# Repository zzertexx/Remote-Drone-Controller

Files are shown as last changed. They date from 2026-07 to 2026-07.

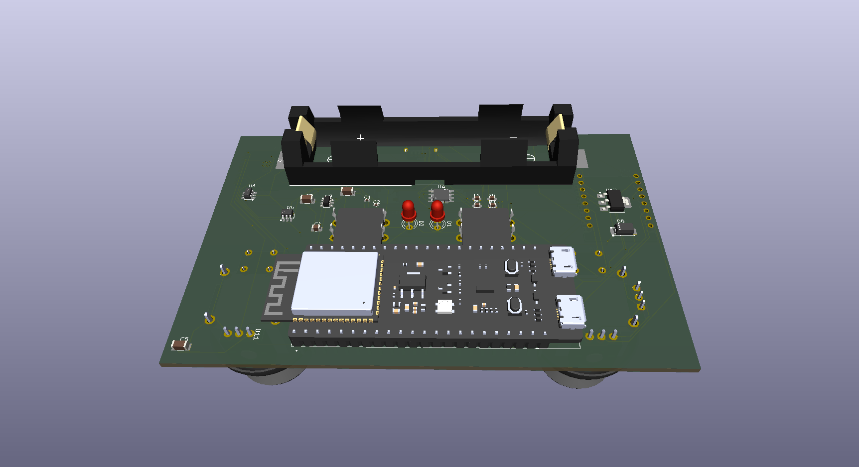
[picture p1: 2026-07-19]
Demo/PCB2.png

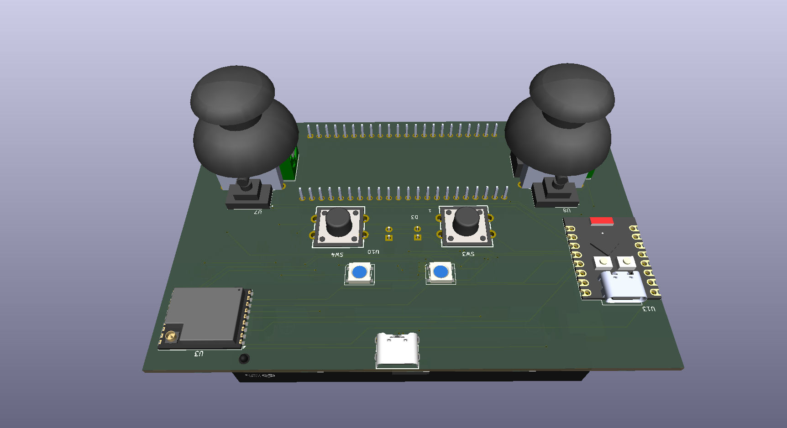
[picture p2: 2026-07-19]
Demo/PCB.png

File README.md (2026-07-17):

# Remote Drone Controller
Remote Controller for my [Drone](https://github.com/zzertexx/drone) with FPV viewer with Phone and Control with Joystick

# How it works
My drone uses ELRS channel to Receive commands and this controller acts as Transmitter on ELRS using SX1280 module while getting joysticks commands from ESP32-C3 that sends them to ESP32-S3.

# How to use it
1. Order PCB
2. Solder all components as stated in Schematics
3. Flash [ELRS firmware](https://github.com/expresslrs/expresslrs) for the main ESP32-S3
4. Flash the companion firmware @ /firmware to the ESP32-C3
5. Power on, bind the controller to drone's ELRS receiver
6. Calibrate joystick min/center/max values.

# Why I designed it?
I designed drone recently, but I don't have controller for it, so I built one

# Bill of Materials
| Name | Quantity |
| --- | --- |
| E28-2G4M27S SX1280 module | 1 pc | 
| ESP32-S3 | 1 pc |
| ESP32-C3 | 1 pc |
| 2.4 GHz antenna  | 1 pc |
| Joystick | 2 pcs |
| TP4056 chip | 1 pc |
| FS8205A chip | 1 pc |
| DW01A chip | 1 pc |
| MT3608 5V converter | 1 pc |
| AMS1117 3.3V converter | 1 pc |
| WS2812 | 2 pcs |
| Tactile Button | 2 pcs |
| Resistors | 1K x3, 1.2K, 100, 4.7K x2, 0, 110K, 15K, 5.1K |
| Inductor 4.7uH | 1 pc |
| Capacitors | 0.1uF x2, 22uF x3, 47uF |
| LED THT D3mm | 2 pcs |
| 2400mAh Battery 18650 | 1 pc |
| Battery Holder | 1 pc |

# Next feautures
3D Enclosure
VTX Video Receiver for Phone

# Photos







# AI DISCLOSURE
AI was used for researching various components, tradeofs and their compatibility

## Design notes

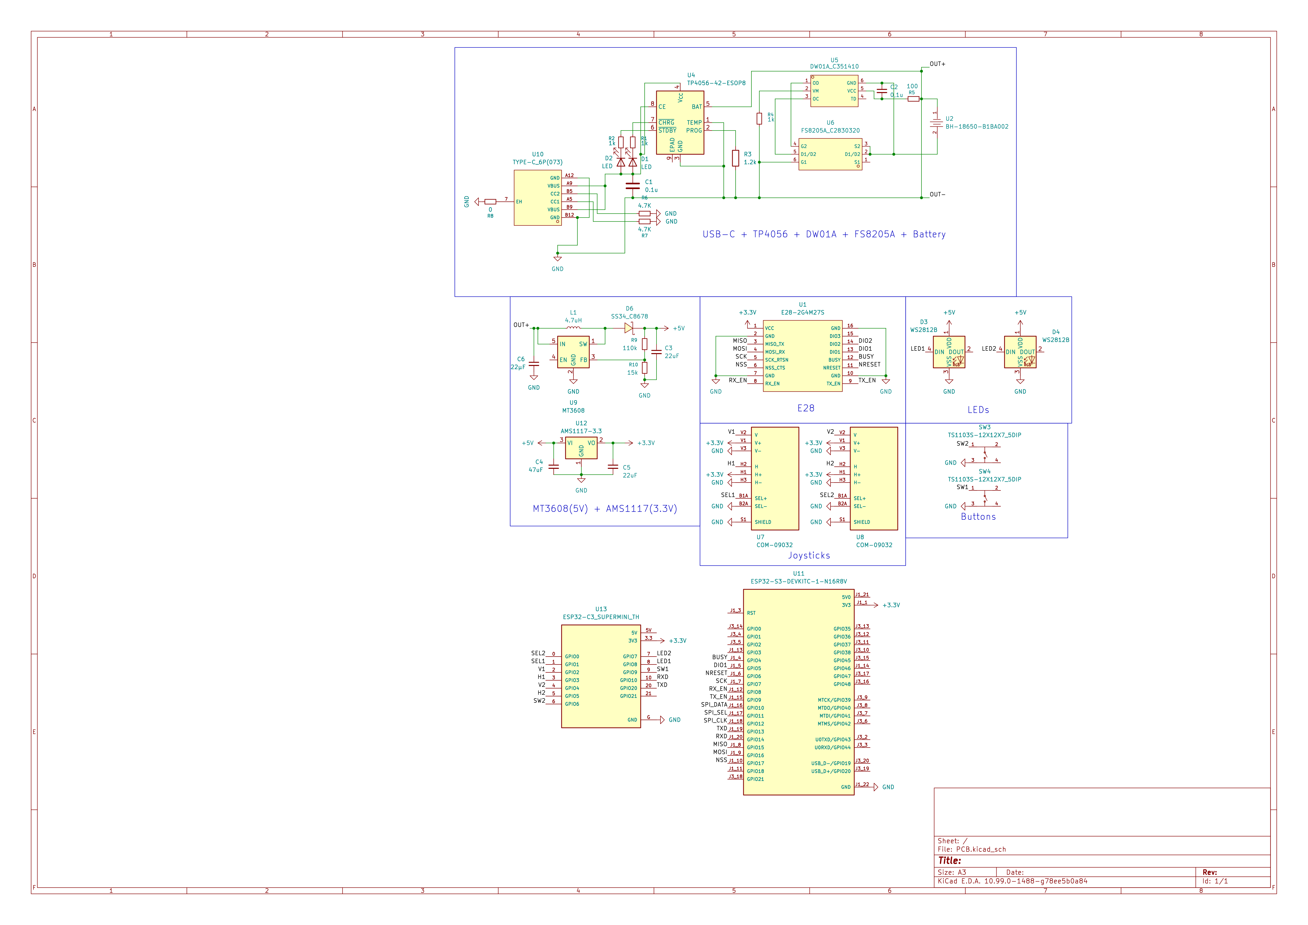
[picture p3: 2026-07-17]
schematics.png

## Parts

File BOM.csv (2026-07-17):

Name | Price USD | Quantity | Link
E28-2G4M27S SX1280 module | 6,2 | 1 | https://item.taobao.com/item.htm?abbucket=3&id=880953544384&ns=1&xxc=taobaoSearch
ESP32-S3N16R8 | 2,22 | 1 | https://item.taobao.com/item.htm?id=872221321968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
MS2107 | 6 | 1 | https://item.taobao.com/item.htm?id=665313273000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
2.4 GHz antenna | 0,6 | 1 | https://detail.tmall.com/item.htm?id=624964877314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
Joystick | 0,6 | 2 | https://detail.tmall.com/item.htm?id=551127183441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
TP4056 chip | 0,07 | 1 | https://item.taobao.com/item.htm?id=981177601023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
DW01A chip | 0,03 | 1 | https://detail.tmall.com/item.htm?abbucket=3&id=762867868512&ns=1&skuId=5253067080369&xxc=taobaoSearch
FS8205A chip | 0,1 | 1 | https://item.taobao.com/item.htm?ali_trackid=282_7bfe62ec76a93e8fbe2256e592906e16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
MT3608 5V converter | 0,037 | 1 | https://item.taobao.com/item.htm?ali_trackid=282_f4fc369ab19dd77611957b498ca91023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
AMS1117 3.3V converter | 0,2 | 1 | https://www.lcsc.com/product-detail/C6186.html?s_z=n_q_AMS1117
WS2812 | 0,74 | 2 | https://item.taobao.com/item.htm?id=522197656009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
Tactile Button | 0,2 | 2 | https://www.lcsc.com/product-detail/C48677982.html?s_z=n_q_t_button
ESP32 C3 | 1,2 | 1 | https://www.lcsc.com/product-detail/C2838500.html?s_z=n_q_p_ESP32%2520C3
Battery Holder | 1,43 | 1 | https://www.lcsc.com/product-detail/C2988620.html?s_z=n_q_t_18650%2520
2400 Battery 18650 | 3,84 | 1 | https://item.taobao.com/item.htm?abbucket=3&id=750556365338&ns=1&xxc=taobaoSearch
THT LEDs 3mm | 0,6 | 1 | https://item.taobao.com/item.htm?id=674866929367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
SS34 Schottky | 0,1 | 1 | https://www.lcsc.com/product-detail/C8678.html?s_z=n_q_x_SS34%2520schottky
22uF capacitor | 0,14 | 3 | https://jlcpcb.com/partdetail/6131-CL31A226KPHNNNE/C5672
47uF capacitor | 0,2 | 1 | https://jlcpcb.com/partdetail/17464-CL21A476MQYNNNE/C16780
0,1uF capacitor | 0,02 | 2 | https://jlcpcb.com/partdetail/1877-CL05B104KO5NNNC/C1525
4.7uH inductor | 0,62 | 1 | https://www.lcsc.com/product-detail/C86090.html
1K resistor | 0,62 | 3 | https://www.lcsc.com/product-detail/C106235.html
1.2K resistor | 0,4 | 1 | https://www.lcsc.com/product-detail/C114605.html
100 resistor | 0,4 | 1 | https://www.lcsc.com/product-detail/C122970.html
4.7K resistor | 0,4 | 2 | https://www.lcsc.com/product-detail/C2907034.html
0 resistor | 0,47 | 1 | https://www.lcsc.com/product-detail/C95177.html
110k resistor | 0,27 | 1 | https://www.lcsc.com/product-detail/C2906984.html
15k resistor | 0,26 | 1 | https://www.lcsc.com/product-detail/C2906995.html
 | 27,967

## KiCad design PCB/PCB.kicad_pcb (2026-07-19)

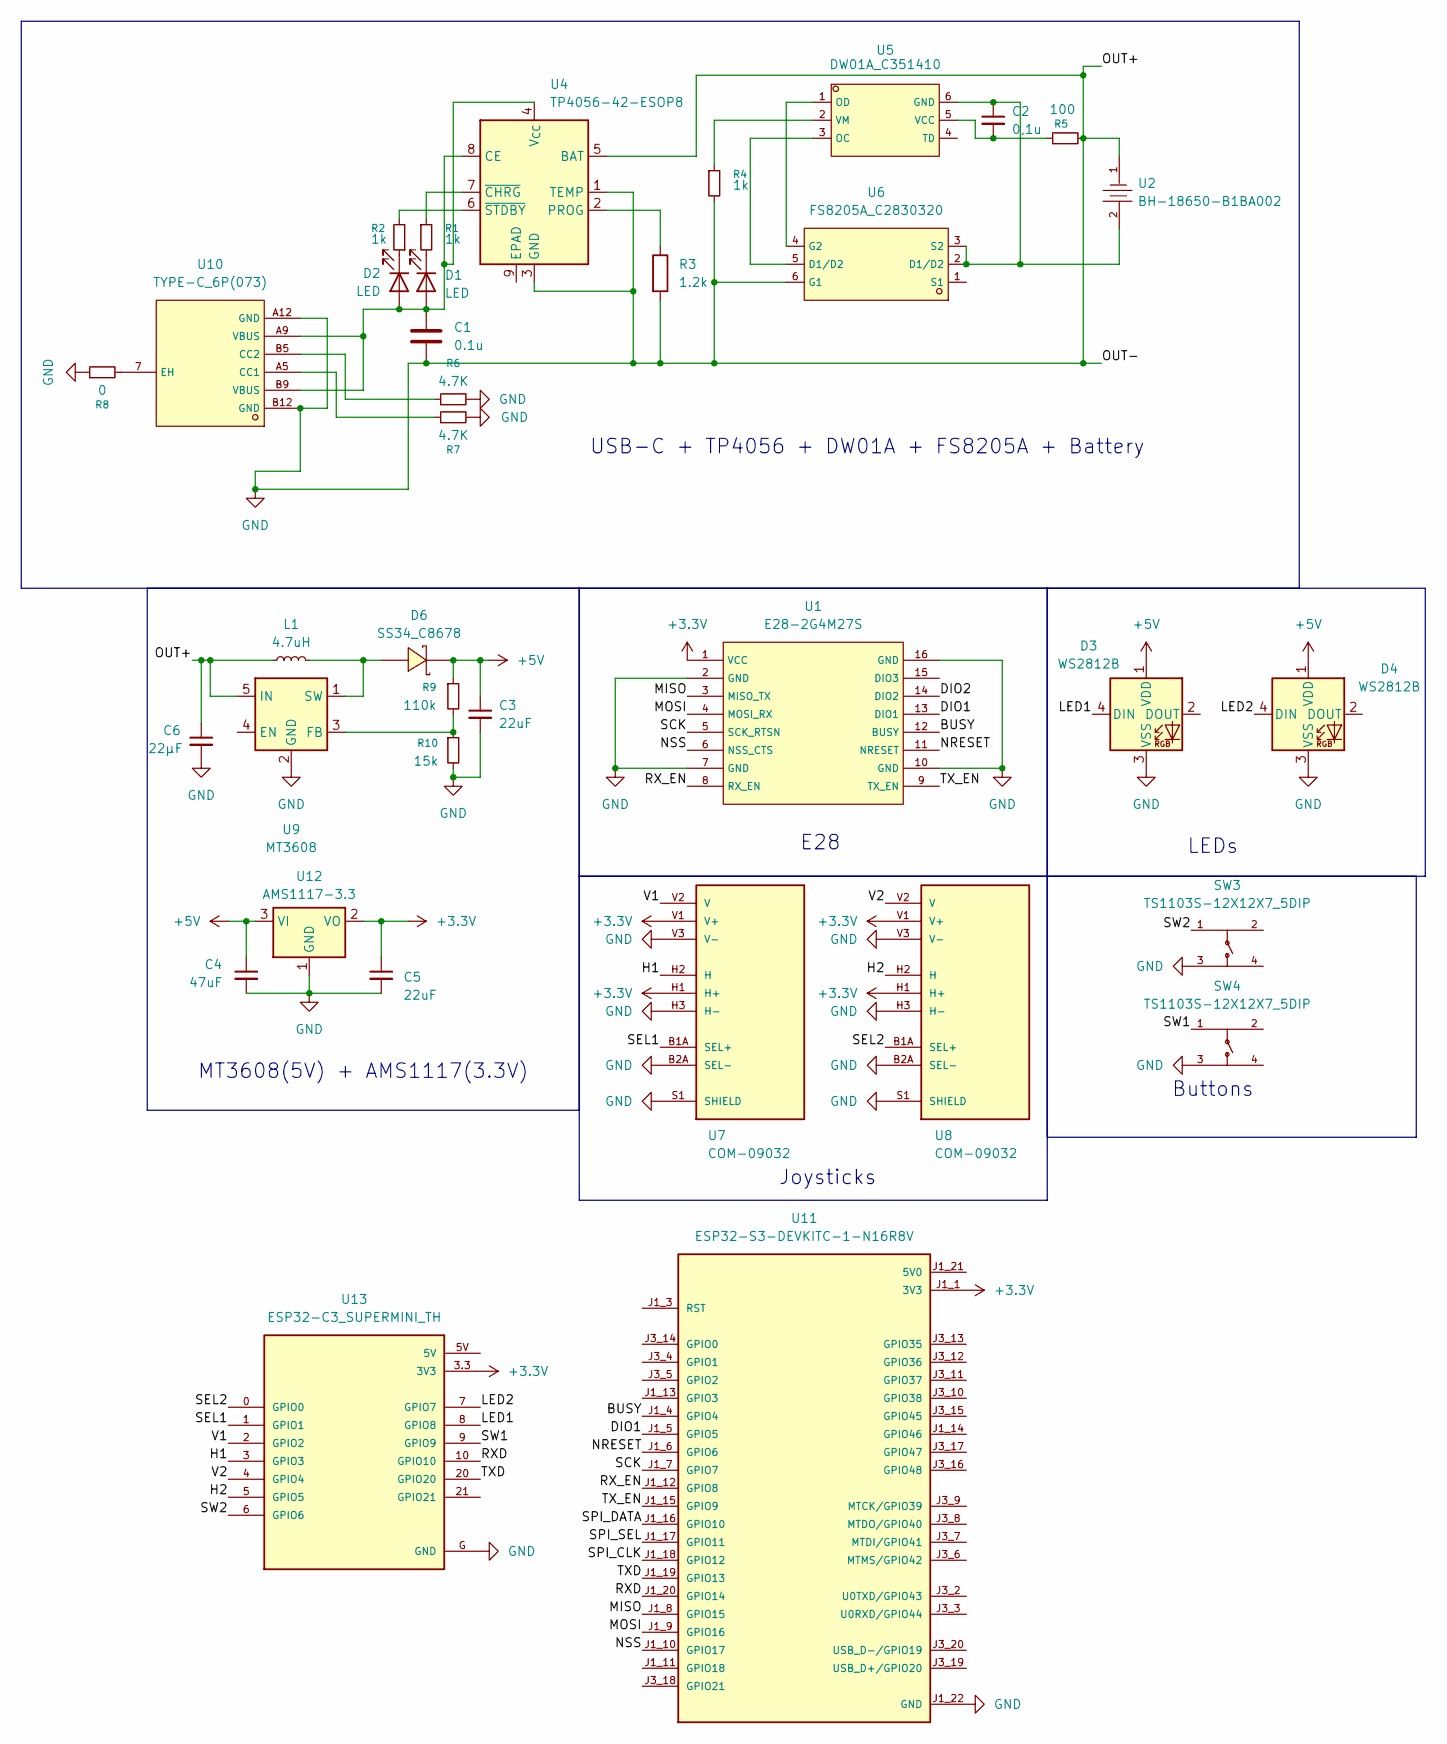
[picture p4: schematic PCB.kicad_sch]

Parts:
C1: 0.1u; C_0402_1005Metric
C2: 0,1u; C_0402_1005Metric
C3, C5: 22uF; C_1206_3216Metric
C4: 47uF; C_0805_2012Metric
C6: 22µF; C_1206_3216Metric
D1, D2: LED; LED_D3.0mm
D3, D4: WS2812B; LED_WS2812B_PLCC4_5.0x5.0mm_P3.2mm
D6: SS34_C8678; SMA_L4.3-W2.6-LS5.2-RD; LCSC C8678
L1: 4.7uH; C_0603_1608Metric
R1, R2, R4: 1k; C_0603_1608Metric
R3: 1.2k; C_0603_1608Metric
R5: 100; C_0603_1608Metric
R6, R7: 4.7K; C_0603_1608Metric
R8: 0; C_0603_1608Metric
R9: 110k; C_0603_1608Metric
R10: 15k; C_0603_1608Metric
SW3, SW4: TS1103S-12X12X7_5DIP; SW-TH_4P-L12.0-W12.0-P5.00-LS12.5; LCSC C48677982
U1: E28-2G4M27S; WIRELM-SMD_E28-2G4M2XS; LCSC C411312
U2: BH-18650-B1BA002; BATTERY-SMD_18650-1S-L77.1-W20.7-1; LCSC C2988620
U4: TP4056-42-ESOP8; SOIC-8-1EP_3.9x4.9mm_P1.27mm_EP2.41x3.3mm_ThermalVias
U5: DW01A_C351410; SOT-23-6_L2.9-W1.6-P0.95-LS2.8-BL; LCSC C351410
U6: FS8205A_C2830320; SOT-23-6_L2.9-W1.6-P0.95-LS2.8-BR; LCSC C2830320
U7, U8: COM-09032; XDCR_COM-09032; PARTREV N/A
U9: MT3608; SOT-23-6
U10: TYPE-C_6P(073); TYPE-C-SMD_TYPE-C-6P-073; LCSC C668623
U11: ESP32-S3-DEVKITC-1-N16R8V; XCVR_ESP32-S3-DEVKITC-1-N16R8V; PARTREV 1.1
U12: AMS1117-3.3; SOT-223-3_TabPin2
U13: ESP32-C3_SUPERMINI_TH; MODULE_ESP32-C3_SUPERMINI_TH

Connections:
+3.3V: C5.1, U1.1 (VCC), U7.H1 (H+), U7.V1 (V+), U8.H1 (H+), U8.V1 (V+), U11.J1_1 (3V3), U11.J1_2 (3V3), U12.2 (VO), U13.3.3 (3V3)
+5V: C3.1, C4.1, D3.1 (VDD), D4.1 (VDD), D6.1 (K), R9.1, U12.3 (VI)
/BUSY: U1.12 (BUSY), U11.J1_4 (GPIO4)
/DIO1: U1.13 (DIO1), U11.J1_5 (GPIO5)
/H1: U7.H2 (H), U13.3 (GPIO3); also elsewhere on the board
/H2: U8.H2 (H), U13.5 (GPIO5); also elsewhere on the board
/LED1: D3.4 (DIN), U13.8 (GPIO8); also elsewhere on the board
/LED2: D4.4 (DIN), U13.7 (GPIO7); also elsewhere on the board
/MISO: U1.3 (MISO_TX), U11.J1_8 (GPIO15)
/MOSI: U1.4 (MOSI_RX), U11.J1_9 (GPIO16)
/NRESET: U1.11 (NRESET), U11.J1_6 (GPIO6)
/NSS: U1.6 (NSS_CTS), U11.J1_10 (GPIO17)
/RXD: U11.J1_20 (GPIO14), U13.10 (GPIO10); also elsewhere on the board
/RX_EN: U1.8 (RX_EN), U11.J1_12 (GPIO8)
/SCK: U1.5 (SCK_RTSN), U11.J1_7 (GPIO7)
/SEL1: U7.B1A (SEL+), U13.1 (GPIO1); also elsewhere on the board
/SEL2: U8.B1A (SEL+), U13.0 (GPIO0); also elsewhere on the board
/SPI_CLK: U11.J1_18 (GPIO12)
/SPI_DATA: U11.J1_16 (GPIO10)
/SPI_SEL: U11.J1_17 (GPIO11)
/SW1: SW4.1, U13.9 (GPIO9); also elsewhere on the board
/SW2: SW3.1, U13.6 (GPIO6); also elsewhere on the board
/TXD: U11.J1_19 (GPIO13), U13.20 (GPIO20); also elsewhere on the board
/TX_EN: U1.9 (TX_EN), U11.J1_15 (GPIO9)
/V1: U7.V2 (V), U13.2 (GPIO2); also elsewhere on the board
/V2: U8.V2 (V), U13.4 (GPIO4); also elsewhere on the board
GND: C1.2, C3.2, C4.2, C5.2, C6.1, C6.2, D3.3 (VSS), D4.3 (VSS), L1.1, R3.2, R4.2, R5.2, R6.2, R7.2, R8.1, R10.2, SW3.3, SW4.3, U1.2 (GND), U1.7 (GND), U1.10 (GND), U1.16 (GND), U2.1, U4.1 (TEMP), U4.3 (GND), U4.5 (BAT), U6.6 (G1), U7.B2A (SEL-), U7.H3 (H-), U7.S1 (SHIELD), U7.S2 (SHIELD), U7.S3 (SHIELD), U7.S4 (SHIELD), U7.V3 (V-), U8.B2A (SEL-), U8.H3 (H-), U8.S1 (SHIELD), U8.S2 (SHIELD), U8.S3 (SHIELD), U8.S4 (SHIELD), U8.V3 (V-), U9.2 (GND), U9.5 (IN), U10.A12 (GND), U10.B12 (GND), U11.J1_22 (GND), U11.J3_1 (GND), U11.J3_21 (GND), U11.J3_22 (GND), U12.1 (GND), U13.G (GND)
unnamed: C1.1, D1.2 (A), D2.2 (A), U4.4 (V_{CC}), U4.8 (CE), U10.A9 (VBUS), U10.B9 (VBUS)
unnamed: D1.1 (K), R1.2
unnamed: D2.1 (K), R2.1
unnamed: D6.2 (A), L1.2, U9.1 (SW)
unnamed: R3.1, U4.2 (PROG)
unnamed: R1.1, U4.7 (~CHRG)
unnamed: R2.2, U4.6 (~STDBY)
unnamed: C2.1, U2.2, U5.6 (GND), U6.2 (D1/D2), U6.3 (S2)
unnamed: U5.3 (OC), U6.5 (D1/D2)
unnamed: U5.1 (OD), U6.4 (G2)
unnamed: C2.2, R5.1, U5.5 (VCC)
unnamed: R4.1, U5.2 (VM)
unnamed: R9.2, R10.1, U9.3 (FB)
unnamed: R7.1, U10.A5 (CC1)
unnamed: R6.1, U10.B5 (CC2)
unnamed: R8.2, U10.7 (EH)

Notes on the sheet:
LEDs
USB-C + TP4056 + DW01A + FS8205A + Battery
MT3608(5V) + AMS1117(3.3V)
Buttons
E28
Joysticks

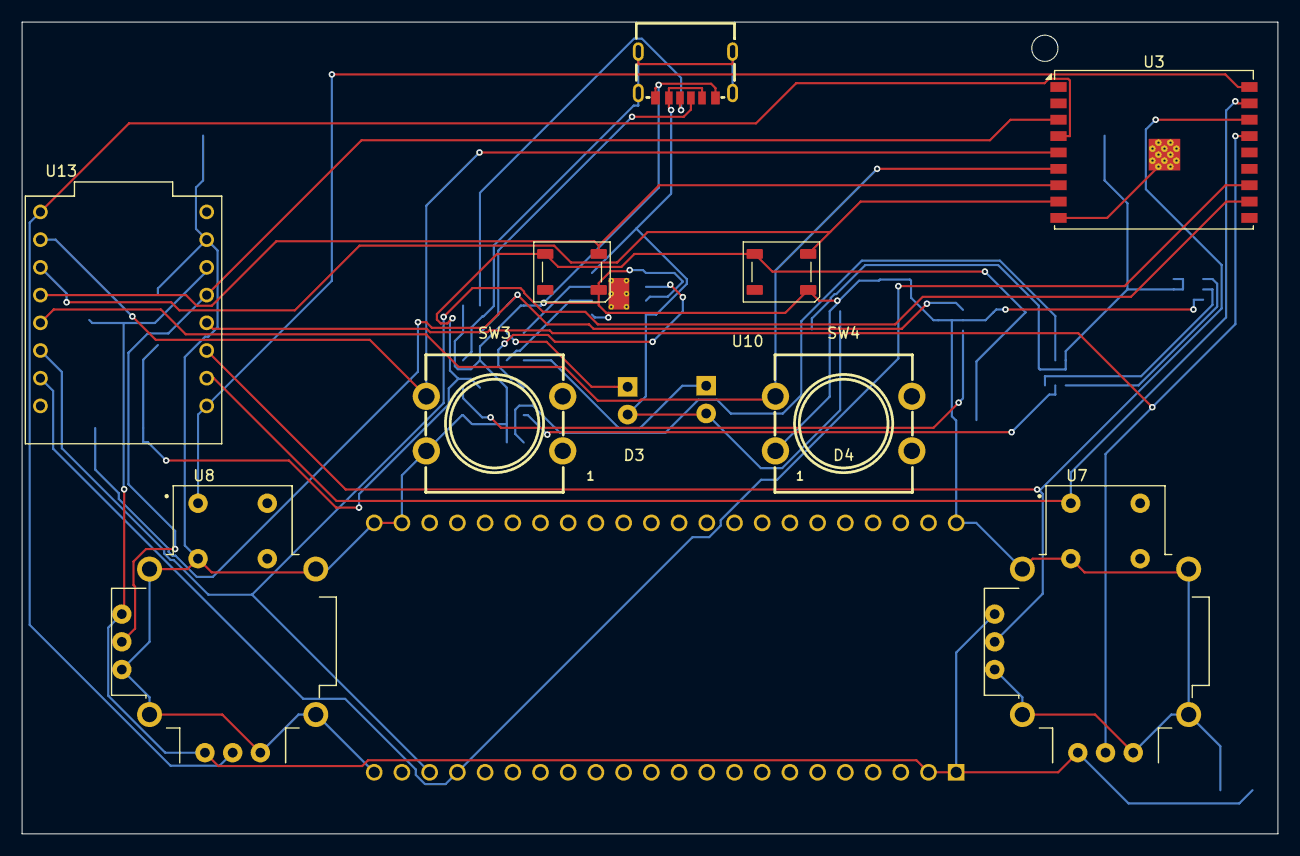
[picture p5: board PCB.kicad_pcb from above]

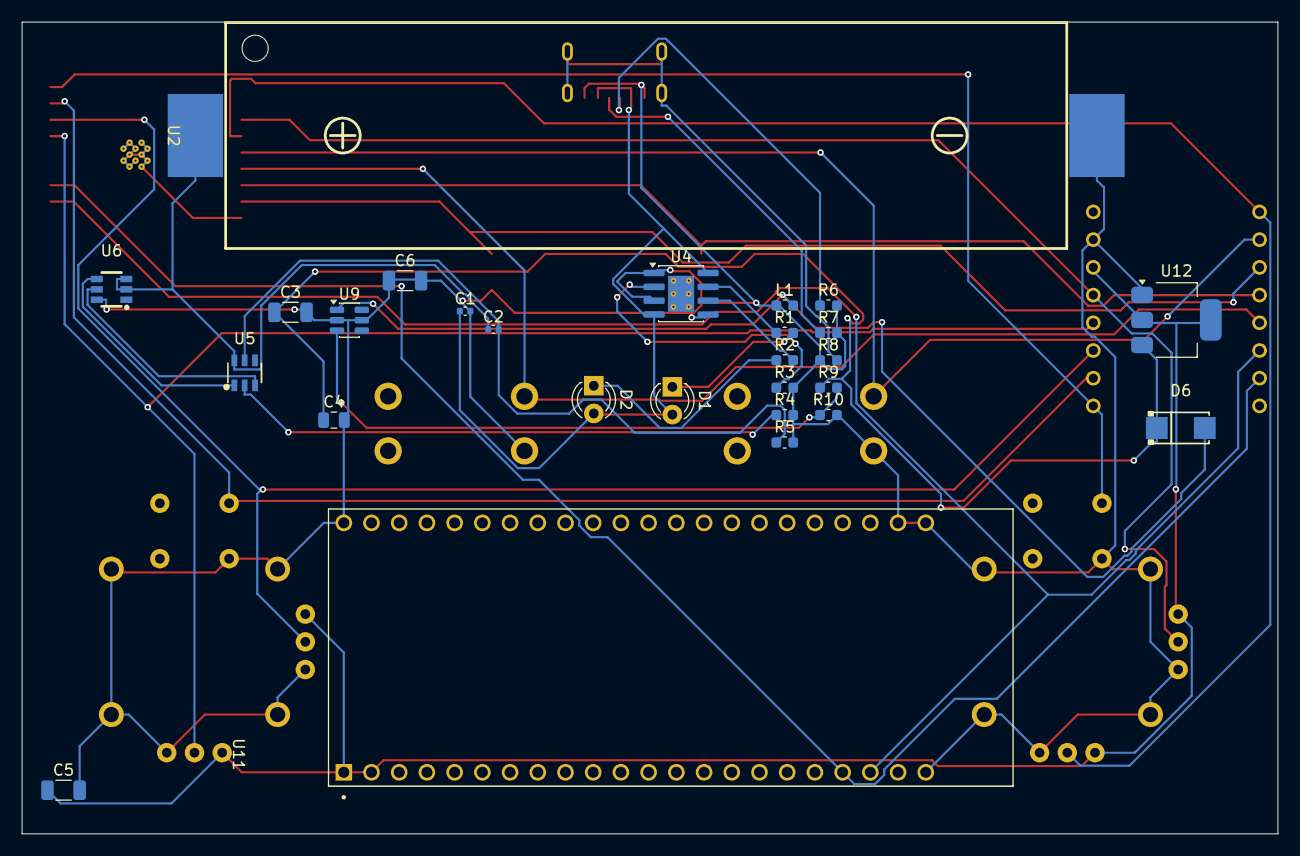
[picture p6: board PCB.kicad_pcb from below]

Board: 2 copper layers, 115.1 x 74.4 mm, 36 parts (27 on the bottom side), 32 nets.

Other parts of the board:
U3: ESP32-C3-WROOM-02U

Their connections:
/H1: U3.15 (IO3); also elsewhere on the board
/H2: U3.4 (IO5); also elsewhere on the board
/LED1: U3.7 (IO8); also elsewhere on the board
/LED2: U3.8 (IO9); also elsewhere on the board
/RXD: U3.11 (IO20/RXD); also elsewhere on the board
/SEL1: U3.17 (IO1); also elsewhere on the board
/SEL2: U3.18 (IO0); also elsewhere on the board
/SW1: U3.6 (IO7); also elsewhere on the board
/SW2: U3.5 (IO6); also elsewhere on the board
/TXD: U3.12 (IO21/TXD); also elsewhere on the board
/V1: U3.16 (IO2); also elsewhere on the board
/V2: U3.3 (IO4); also elsewhere on the board
unnamed: U3.9 (GND), U3.19 (GND)

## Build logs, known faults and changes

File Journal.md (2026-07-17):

---
title: "Remote Drone Controller"
author: "Alimzhan Karash"
description: "Remote Controller for my Drone with FPV viewer with Phone and Control with Joystick"
created_at: "2026-07-17"
---

# July 16th: Locked-in and finished basics

[In one day I finished particularly every main feauture. I designed schematics, PCB, firmware and organized repo. Next feautres would be adding 3D case enclosure and VTX video receiver]





**Total time spent: 7h:30min**

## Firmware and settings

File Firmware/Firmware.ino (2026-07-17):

#include <Adafruit_NeoPixel.h>

#define V1_PIN            0 
#define H1_PIN            1  
#define V2_PIN            2  
#define H2_PIN            3   
#define SEL2_PIN          4  
#define SW2_PIN           6  
#define LED2_PIN          7 
#define LED1_PIN          8   
#define SW1_PIN           9   
#define RXD_PIN           10  
#define TXD_PIN           20  
#define SEL1_PIN          21  

#define CRSF_BAUD         420000

#define CRSF_SYNC_BYTE                     0xC8
#define CRSF_FRAMETYPE_RC_CHANNELS_PACKED  0x16
#define CRSF_FRAMETYPE_LINK_STATISTICS     0x14
#define CRSF_CHANNEL_VALUE_MIN   172   
#define CRSF_CHANNEL_VALUE_MID   992   
#define CRSF_CHANNEL_VALUE_MAX   1811  

#define ELRS_ADDRESS          0xEE
#define ADDR_RADIO             0xEA
#define ELRS_BIND_COMMAND      0xFF
#define TYPE_SETTINGS_WRITE    0x2D

Adafruit_NeoPixel led1(1, LED1_PIN, NEO_GRB + NEO_KHZ800);
Adafruit_NeoPixel led2(1, LED2_PIN, NEO_GRB + NEO_KHZ800);

uint16_t channels[16];

uint8_t crc8_dvb_s2(uint8_t crc, uint8_t a) {
  crc ^= a;
  for (int i = 0; i < 8; i++) {
    crc = (crc & 0x80) ? (crc << 1) ^ 0xD5 : (crc << 1);
  }
  return crc;
}

uint8_t crc8_buf(uint8_t *data, uint8_t len) {
  uint8_t crc = 0;
  for (uint8_t i = 0; i < len; i++) crc = crc8_dvb_s2(crc, data[i]);
  return crc;
}

uint16_t adcToCrsf(int adcValue, int adcMin, int adcMid, int adcMax) {
  adcValue = constrain(adcValue, adcMin, adcMax);
  if (adcValue < adcMid) {
    return map(adcValue, adcMin, adcMid, CRSF_CHANNEL_VALUE_MIN, CRSF_CHANNEL_VALUE_MID);
  }
  return map(adcValue, adcMid, adcMax, CRSF_CHANNEL_VALUE_MID, CRSF_CHANNEL_VALUE_MAX);
}

void sendCrsfChannels() {
  uint8_t frame[26];
  uint8_t payload[22];
  memset(payload, 0, sizeof(payload));

  uint32_t bitBuffer = 0;
  int bitsInBuffer = 0;
  int byteIndex = 0;

  for (int ch = 0; ch < 16; ch++) {
    bitBuffer |= ((uint32_t)(channels[ch] & 0x7FF)) << bitsInBuffer;
    bitsInBuffer += 11;
    while (bitsInBuffer >= 8) {
      payload[byteIndex++] = bitBuffer & 0xFF;
      bitBuffer >>= 8;
      bitsInBuffer -= 8;
    }
  }
  if (bitsInBuffer > 0) payload[byteIndex++] = bitBuffer & 0xFF;

  frame[0] = CRSF_SYNC_BYTE;
  frame[1] = 22 + 2;
  frame[2] = CRSF_FRAMETYPE_RC_CHANNELS_PACKED;
  memcpy(&frame[3], payload, 22);
  frame[25] = crc8_buf(&frame[2], 23);

  Serial1.write(frame, 26);
}

void sendBindCommand() {
  uint8_t packet[8];
  packet[0] = ELRS_ADDRESS;
  packet[1] = 6;
  packet[2] = TYPE_SETTINGS_WRITE;
  packet[3] = ELRS_ADDRESS;
  packet[4] = ADDR_RADIO;
  packet[5] = ELRS_BIND_COMMAND;
  packet[6] = 0x01;
  packet[7] = crc8_buf(&packet[2], 5);
  Serial1.write(packet, 8);
}

void updatePowerLED() {
  led1.setPixelColor(0, led1.Color(40, 40, 40));
  led1.show();
}

volatile bool droneConnected = false;
volatile unsigned long lastTelemetryMillis = 0;
#define TELEMETRY_TIMEOUT_MS 1000

void updateConnectionLED() {
  bool connected = droneConnected && (millis() - lastTelemetryMillis < TELEMETRY_TIMEOUT_MS);
  led2.setPixelColor(0, connected ? led2.Color(0, 255, 0) : led2.Color(255, 0, 0));
  led2.show();
}

uint8_t rxBuf[64];
uint8_t rxIndex = 0;

void pollCrsfTelemetry() {
  while (Serial1.available()) {
    uint8_t b = Serial1.read();
    if (rxIndex == 0 && b != CRSF_SYNC_BYTE) continue;
    rxBuf[rxIndex++] = b;

    if (rxIndex >= 2) {
      uint8_t frameLen = rxBuf[1];
      if (rxIndex >= frameLen + 2) {
        uint8_t expectedCrc = rxBuf[frameLen + 1];
        uint8_t actualCrc = crc8_buf(&rxBuf[2], frameLen - 1);
        if (expectedCrc == actualCrc && rxBuf[2] == CRSF_FRAMETYPE_LINK_STATISTICS) {
          droneConnected = true;
          lastTelemetryMillis = millis();
        }
        rxIndex = 0;
      }
    }
    if (rxIndex >= sizeof(rxBuf)) rxIndex = 0;
  }
}

bool lastSW2State = HIGH;
bool lastSW1State = HIGH;
unsigned long sw1PressStart = 0;
#define SW1_LONGPRESS_MS 1500

void handleButtons() {
  bool sw2State = digitalRead(SW2_PIN);
  if (sw2State == LOW && lastSW2State == HIGH) {
    sendBindCommand();
  }
  lastSW2State = sw2State;

  bool sw1State = digitalRead(SW1_PIN);
  if (sw1State == LOW && lastSW1State == HIGH) {
    sw1PressStart = millis();
  }
  if (sw1State == LOW && (millis() - sw1PressStart > SW1_LONGPRESS_MS)) {
    led1.setPixelColor(0, 0); led1.show();
    led2.setPixelColor(0, 0); led2.show();
    gpio_wakeup_enable((gpio_num_t)SW1_PIN, GPIO_INTR_LOW_LEVEL);
    esp_sleep_enable_gpio_wakeup();
    esp_deep_sleep_start();
  }
  lastSW1State = sw1State;

  channels[6] = (digitalRead(SEL1_PIN) == LOW) ? CRSF_CHANNEL_VALUE_MAX : CRSF_CHANNEL_VALUE_MIN;
  channels[7] = (digitalRead(SEL2_PIN) == LOW) ? CRSF_CHANNEL_VALUE_MAX : CRSF_CHANNEL_VALUE_MIN;
}

void readJoysticks() {
  int adcMin = 100, adcMid = 2048, adcMax = 3995;

  int v1Raw = analogRead(V1_PIN);
  int h1Raw = analogRead(H1_PIN);
  int v2Raw = analogRead(V2_PIN);
  int h2Raw = analogRead(H2_PIN);

  channels[0] = adcToCrsf(h2Raw, adcMin, adcMid, adcMax); 
  channels[1] = adcToCrsf(v2Raw, adcMin, adcMid, adcMax); 
  channels[2] = adcToCrsf(v1Raw, adcMin, adcMid, adcMax); 
  channels[3] = adcToCrsf(h1Raw, adcMin, adcMid, adcMax); 
}

void setup() {
  Serial1.begin(CRSF_BAUD, SERIAL_8N1, RXD_PIN, TXD_PIN);

  pinMode(SW1_PIN, INPUT_PULLUP);
  pinMode(SW2_PIN, INPUT_PULLUP);
  pinMode(SEL1_PIN, INPUT_PULLUP);
  pinMode(SEL2_PIN, INPUT_PULLUP);

  led1.begin();
  led2.begin();
  led1.setBrightness(80);
  led2.setBrightness(80);
  led1.show();
  led2.show();

  for (int i = 0; i < 16; i++) channels[i] = CRSF_CHANNEL_VALUE_MID;
}

unsigned long lastChannelSend = 0;
#define CHANNEL_SEND_INTERVAL_MS 4 

void loop() {
  pollCrsfTelemetry();
  handleButtons();
  readJoysticks();

  if (millis() - lastChannelSend >= CHANNEL_SEND_INTERVAL_MS) {
    sendCrsfChannels();
    lastChannelSend = millis();
  }

  updatePowerLED();
  updateConnectionLED();
}
